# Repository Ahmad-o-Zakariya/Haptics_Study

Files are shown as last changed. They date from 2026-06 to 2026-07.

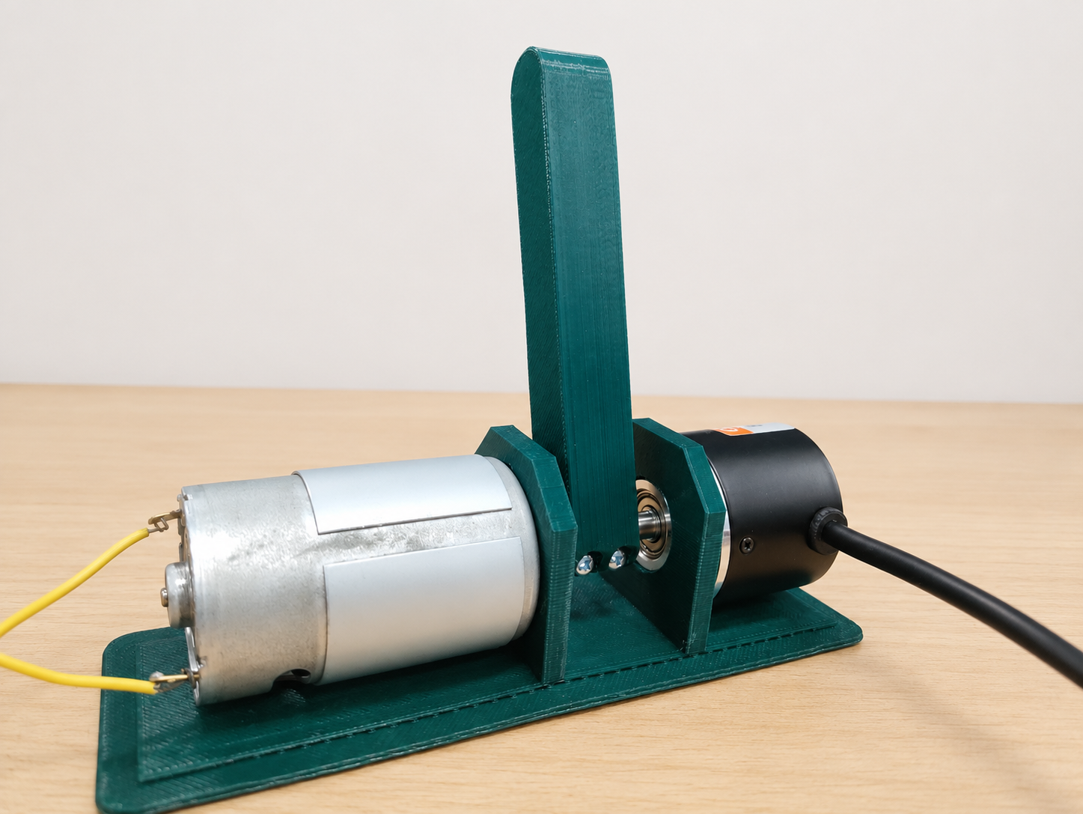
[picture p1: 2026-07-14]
1_kHz_haptic_control_loop/1 DOF Haptic setup.png

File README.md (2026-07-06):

# Haptics_Study

A collection of embedded haptic rendering experiments developed on the **ATmega328P (Arduino Uno)** platform. This repository documents the evolution of a **1-DOF force-feedback haptic interface**, from a production-grade virtual wall renderer to advanced research implementations including **fractional-order viscoelastic models**, **dual-rate control**, **direct port manipulation**, and multiple motor driver configurations.

The project began as a high-performance virtual wall implementation and has since evolved into a research platform for studying real-time embedded haptic rendering, control system stability, and computational optimization on resource-constrained microcontrollers.

Following successful validation and technical review by senior faculty, the original virtual wall implementation was officially approved as the benchmark instructional demonstration layout for incoming first-year engineering students.

---

# 📂 Repository Structure

```text
Haptics_Study/
│
├── 1_kHz_haptic_control_loop/
│   └── 1_kHz_haptic_control_loop.ino
│
├── Direct_Port_Manipulation/
│   └── Direct_Port_Manipulation.ino
│
├── Dual_Rate_FO-SLS_model/
│   └── Dual_Rate_FO-SLS_model.ino
│
├── Fractional_Order_Kelvin_Voigt_Model/
│   ├── Fractional_Order_Kelvin_Voigt_Model.ino
│   ├── graphs.py
│   └── haptic_plotter.py
│
├── Fractional_Order_SLS-Model/
│   ├── Fractional_Order_SLS-Model.ino
│   └── simulation_test.py
│
├── LMD18200T_Code/
│   └── LMD18200T_Code.ino
│
├── MD10C_R3_Code/
│   └── MD10C_R3_Code.ino
│
├── 3d-drawings/
│   └── Mechanical CAD (.stl) files
│
├── Paper and Notes/
│   └── Research papers, technical reports, lecture notes
│
├── haptic_with_noise.ino
└── README.md
```

---

# 📁 Project Overview

## 1️⃣ 1_kHz_haptic_control_loop

The primary production implementation.

**Features**

- Deterministic **1 kHz real-time control loop**
- Native **32-bit integer arithmetic**
- Embedded **2nd-order Butterworth low-pass filter**
- Passivity constraint protection
- Downsampled telemetry
- Optimized for the **L298N** motor driver

This serves as the baseline implementation for the remainder of the repository.

---

## 2️⃣ Direct_Port_Manipulation

Experimental implementation replacing Arduino API calls with direct manipulation of AVR hardware registers.

**Goals**

- Reduced instruction latency
- Lower interrupt overhead
- Faster GPIO transitions
- Improved deterministic timing

---

## 3️⃣ Fractional_Order_SLS_Model

Implements a **Fractional-Order Standard Linear Solid (FO-SLS)** virtual wall model.

Unlike a traditional spring-damper wall, this model captures viscoelastic behavior using fractional calculus, allowing more realistic rendering of compliant materials.

Includes simulation utilities for validating model behavior.

---

## 4️⃣ Fractional_Order_Kelvin_Voigt_Model

Implements a **Fractional Kelvin-Voigt** viscoelastic virtual environment.

Includes Python utilities for:

- Force visualization
- Experimental plotting
- Offline analysis

---

## 5️⃣ Dual_Rate_FO-SLS_Model

Experimental implementation combining:

- Dual-rate sampling
- Fractional-order viscoelastic rendering

to investigate stability improvements under computational constraints.

---

## 6️⃣ LMD18200T_Code

Version of the controller adapted for the **LMD18200T** high-current motor driver.

Designed for applications requiring:

- Higher continuous current
- Improved efficiency
- Industrial-grade motor control

---

## 7️⃣ MD10C_R3_Code

Alternative implementation supporting the **Cytron MD10C R3** motor driver.

Provides compatibility with PWM/Direction control architectures.

---

## 8️⃣ haptic_with_noise.ino

Legacy implementation preserved for educational comparison.

Characteristics:

- Floating-point computations
- Backward-difference velocity estimation
- Unrestricted serial logging
- Unstable loop timing

Useful for demonstrating common real-time control pitfalls.

---

## 9️⃣ 3d-drawings

Contains all mechanical CAD models used throughout development.

Includes multiple revisions of:

- Motor couplers
- Encoder couplers
- Shaft assemblies
- Handle assemblies
- Mounting structures

The designs evolved toward minimizing backlash while maximizing torsional rigidity.

---

## 📚 Paper and Notes

A curated collection of:

- Journal papers
- Conference publications
- Thesis material
- Technical reports
- Engineering notes

covering:

- Haptic rendering
- Fractional-order control
- Dual-rate systems
- Virtual wall stability
- Motor control
- Wave-variable haptics
- Embedded control

These documents served as the primary research references throughout development.

---

# ⚡ Hardware Configuration (Baseline L298N System)

## Power Supply

**MIMY RoHS S-120-12**

Provides:

- 12 V DC
- 10 A maximum current

| Terminal | Connection |
|---|---|
| L | AC Live |
| N | AC Neutral |
| Earth | Safety Ground |
| -V | L298N Ground |
| +V | L298N +12V |

---

## L298N Driver

| Pin | Connection |
|---|---|
| 12V | Power Supply +12V |
| GND | Common Ground (Power Supply + Arduino) |
| 5V | Not Connected |
| ENA | Arduino Pin 5 (PWM) |
| IN1 | Arduino Pin 4 |
| IN2 | Arduino Pin 7 |
| OUT1 / OUT2 | DC Motor |

PWM is applied through **ENA**, while **IN1/IN2** determine motor direction.

---

## Optical Quadrature Encoder

Base resolution:

**400 PPR**

Effective resolution:

**1600 Counts Per Revolution (4× decoding)**

| Encoder | Arduino |
|---|---|
| VCC | 5V |
| GND | GND |
| Phase A | Pin 2 (Interrupt 0) |
| Phase B | Pin 3 (Interrupt 1) |

---

# 🧠 Engineering Development Journey

## Phase 1 — Eliminating the Serial Bottleneck

High-frequency `Serial.print()` operations saturated the UART transmit buffer, reducing the control loop from **1 kHz** to approximately **400 Hz**.

**Solution**

- Decoupled telemetry from control calculations
- Downsampled serial output to **40 Hz**
- Maintained deterministic **1 kHz** execution

---

## Phase 2 — Correct PWM Architecture

Early implementations modulated PWM through direction pins, producing asymmetric motor behavior and excessive dynamic braking.

**Solution**

- Fixed digital direction lines (`IN1`, `IN2`)
- PWM exclusively through `ENA`

---

## Phase 3 — Velocity Filtering

Backward-difference differentiation amplified encoder quantization noise.

**Solution**

A second-order Butterworth IIR low-pass filter configured with:

- Sampling frequency: **1000 Hz**
- Cutoff frequency: **100 Hz**

This significantly reduced quantization artifacts while preserving low phase delay.

---

## Phase 4 — Integer Arithmetic Optimization

The ATmega328P lacks hardware floating-point support.

The controller was rewritten entirely in native integer count space, reducing computational overhead and improving deterministic execution.

---

## Phase 5 — Transparency vs Stability

Adding ambient damping improved stability but reduced free-space transparency.

The production implementation therefore omits background damping, relying instead on:

- Optimized controller gains
- Mechanical damping
- Rigid zero-backlash transmission

to preserve a natural haptic experience.

---

# 🛠️ Virtual Wall Model

The unilateral virtual wall is represented by a discrete spring-damper model:

$$
F_{\text{wall}} = -(K \Delta x + B\,v_{\text{filtered}})
$$

where force is generated only after the handle penetrates the virtual wall boundary.

### Baseline Parameters

| Parameter | Value |
|---|---|
| Wall Position | 400 counts (90°) |
| Stiffness | 22.5 PWM/count |
| Damping | 0.09 PWM/count/s |
| Maximum PWM | 200 |

---

# 🎯 Research Topics Covered

This repository explores multiple aspects of embedded haptic rendering, including:

- Classical virtual wall rendering
- Fractional-order viscoelastic modeling
- Standard Linear Solid (SLS) models
- Kelvin-Voigt models
- Dual-rate haptic rendering
- Direct AVR register manipulation
- Embedded real-time optimization
- Motor driver comparison (L298N, MD10C, LMD18200T)
- Mechanical transmission design
- Stability and passivity analysis
- Digital filtering
- Low-latency control systems

---

# 📄 License

This repository is intended for educational, research, and instructional use. Contributions and experimentation are encouraged.

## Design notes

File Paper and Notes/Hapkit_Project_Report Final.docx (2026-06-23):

Precision-Engineered Hapkit for Enhanced Haptic Feedback

Final Year Project Report

Submitted to the Department of Mechanical Engineering

In the partial fulfilment of the

Requirements for the degree of

Bachelor of Technology (B.Tech)

Isha Zargar

Maria

Supervised by:

Prof. Babar Ahmad

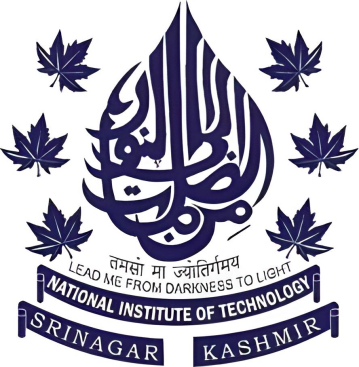
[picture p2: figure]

Department of Mechanical Engineering

National Institute of Technology

Srinagar—190006 India

July 2025

Declaration

We certify that:

a. The work contained in this report is original and has been done by us under the guidance of our supervisor.
b. The work has not been submitted to any other institute for any degree or diploma.
c. We have followed the guidelines provided by the institute in preparing the report.
d. We have conformed to the norms and guidelines given in the Ethical Code of Conduct of the Institute.
e. Whenever we have used materials (data, theoretical analysis, figures, and text) from other sources,
f. We have given due credit to them by citing them in the text of the report and giving their details in the references.

Further, we have taken permission from the copyright owners of the sources whenever necessary.

Isha Zargar (2021BMEC039)

Maria (2021BMEC037)

Certificate

This is to certify that the project work contained in the project report titled “Precision Engineered Hapkit for Haptic Feedback” submitted by “Isha Zargar and Maria” to the Department of Mechanical Engineering, National Institute of Technology Srinagar, J&K, India, is a record of bonafide project work carried out by them under my supervision and guidance and is worthy of consideration for the award of the degree of Bachelor of Technology in Mechanical Engineering of the Institute.

Supervisor

Professor Babar Ahmad

Co-Supervisor

Dr Suhail G. Khosa

Head of Department

Dr MF Wani

Date:

# Abstract

Haptics, the study and application of tactile feedback technology, plays a vital role in enhancing human interaction with machines, particularly in fields that demand precision and intuitive control. With applications spanning medical training, virtual reality, and remote manipulation, haptic devices serve as essential tools for simulating real-world physical interactions within digital environments.

This report presents the development and implementation of a haptic interface using a Hapkit — a low-cost, open-source, one-degree-of-freedom haptic device designed by Stanford University. The objective of this project was to assemble, calibrate, and program the Hapkit to demonstrate force feedback in real time, allowing users to interact with a virtual environment through physical motion. The design includes custom 3D-printed components, a DC motor, an optical sensor for position tracking, and an Arduino-based control system to regulate force rendering based on user input.

The project emphasizes accessibility and modularity, allowing further experimentation in human-computer interaction, motor learning, and virtual training scenarios. By successfully integrating mechanical design, sensor feedback, and control programming, this work demonstrates how haptic technology can be both educational and impactful, paving the way for deeper exploration in the rapidly growing field of tactile feedback systems.

# Acknowledgments

First and foremost, we express our deepest gratitude to the Almighty for granting us the strength, determination, and perseverance to successfully complete our final year project. We are profoundly thankful to our project supervisor, Prof. Babar Ahmad, Department of Mechanical Engineering, NIT Srinagar, for his invaluable guidance, constant encouragement, and unwavering support throughout the course of this project. His deep insight and belief in our capabilities were instrumental in navigating challenging phases of our work.

We also extend our sincere thanks to Prof. M.F.Wani, Head of the Department of Mechanical Engineering, NIT Srinagar, for providing us with essential departmental resources and a conducive environment to carry out our research.

A special note of appreciation goes to Dr. Suhail G Khosa at the Haptics and Mechatronics Devices (HAMD) Lab, whose assistance and expertise significantly contributed to the successful execution of this multidisciplinary project.

Isha Zargar (2021BMEC039)

Maria (2021BMEC037)

# List of Figures

# 2 Introduction

## 2.1 Overview of Haptics:

"Haptics" is derived from the Greek verb "haptesthai," which pertains to the sense of touch. Within the realms of psychology and neuroscience, haptics encompasses the investigation of human perception and manipulation of objects via tactile sensory modalities. This field incorporates kinesthetic sensors, which are responsible for detecting force and position, as well as cutaneous sensors, which are tasked with recognizing tactile sensations. The sense of touch can be categorized as either cutaneous or kinesthetic, contingent upon the type of neural inputs received by the brain. The cutaneous (tactile) system employs receptors located within the skin, whereas the kinesthetic system utilizes receptors found in muscles, tendons, and joints.

Haptics represents a significant area of research in robotics and virtual reality, focusing on the examination of tactile interactions—both physical and virtual—among humans, robots, and real or simulated environments. The integration of haptic technology with robotics is largely attributed to its reliance on advanced mechatronic systems. Haptic interfaces harness mechatronic devices and computerized controls to replicate or enhance the tactile sensations associated with perceiving or manipulating objects in the physical domain. This capability to reproduce authentic physical experiences or to generate entirely novel sensations greatly augments human-computer interaction (HCI) and the modalities of our interactions with technology.

## 2.2 Significance of Haptic Technology

Haptic technology refers to the field of science that bridges the gap between mechanical systems and the human sense of touch. It enables users to receive tactile sensations—such as pressure, vibration, or resistance—through an interface that replicates real-world interactions within virtual environments. This process, known as haptic feedback, allows for a two-way flow of information between human users and digital systems, where virtual responses are physically felt by the user based on the simulated environment.

The primary objective of haptics is to enhance realism in simulations and improve user immersion by mimicking the sensations encountered during real-life interactions. Through the integration of actuators and sensors, haptic systems replicate the feel of manipulating physical objects—even when they only exist in digital form. Haptic technology has grown beyond its initial applications in gaming and consumer electronics to become a cornerstone in fields such as medical training, robotics, virtual reality (VR), rehabilitation, and education. By enabling physical interaction with digital systems, haptics facilitates intuitive control, enhanced realism, and muscle memory development—attributes that are critical in both professional and learning environments.

For instance, haptic feedback systems are increasingly employed in rehabilitative devices aimed at aiding stroke survivors or patients with motor impairments; for example, exoskeleton gloves fitted with force feedback mechanisms allow users to regain lost hand movement by mimicking natural motion and providing resistance during therapy. This method encourages muscle reactivation and neuroplasticity.

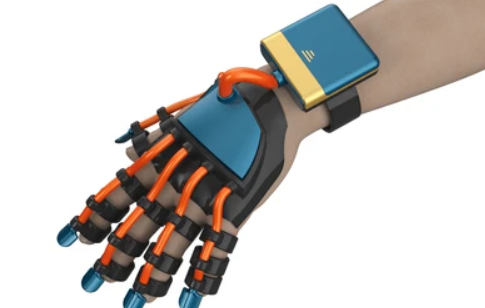
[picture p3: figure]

Figure 1: Exoskeleton Gloves

Moreover, advanced prosthetic limbs equipped with haptic sensors allow amputees to perceive pressure, texture, or even temperature. Sensors on the artificial limb send signals back to the residual limb, often through vibration or electrical stimulation, offering a more intuitive control experience.

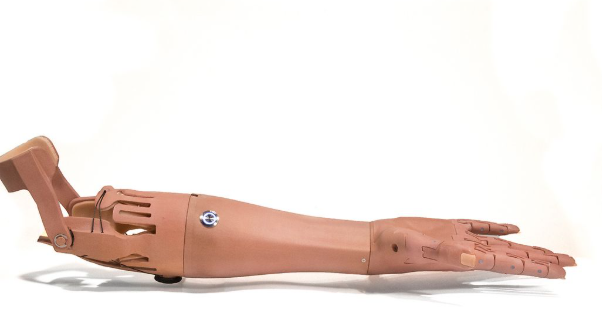
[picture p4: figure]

Figure 2 Advanced Prosthetic Limbs

Rehabilitation is one of the most promising frontiers for haptic technology. Patients recovering from neurological disorders like stroke or cerebral palsy often require repetitive motor training with physical guidance. As illustrated in, digital virtual environments are full of tools that enhance user immersion and decision-making processes, including haptic devices.

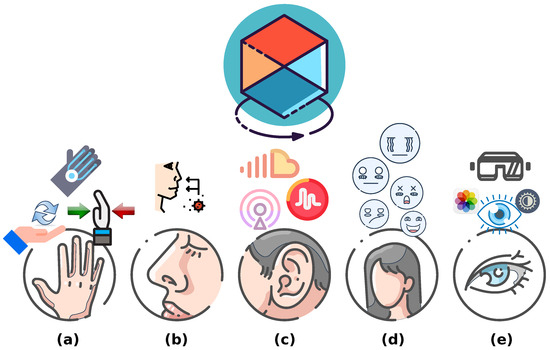
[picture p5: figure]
Sensors 24 06946 g001

Figure 3. Environment–user virtual interactions: (a) Touching: Generating sensations such as pain, pressure, temperature, etc. (b) Smelling: Producing sensitivity to odors, aromas, flavors, etc. (c) Listening: Transmitting sounds, rhythms, tunes, etc. (d) Feelings: Eliciting emotions and a comfortable atmosphere. (e) Vision: Generating accessible virtual environments.

Similarly, the gaming industry has seen a dramatic transformation with the integration of haptic technologies. Haptic devices enrich the gaming experience by simulating realistic touch sensations corresponding to in-game events. These sensations can include vibrations, resistance, textures, and force feedback, making the virtual environment feel physically tangible. For instance, Razer Freyja (Figure 4) is a computer chair pad that allows players to experience physical vibrations while gaming. The device provides realistic tactile sensations that match the events in the game, from the vibration of a race car engine to the tense silence during a covert mission.

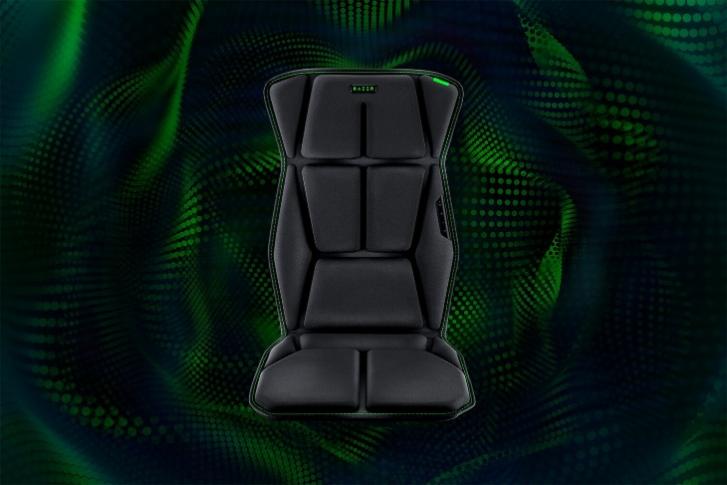
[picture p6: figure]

Figure 4 Razer Freyja Gaming Pad

In traditional console and mobile games, basic vibration motors in controllers or smartphones provide feedback when, for example, a player crashes a car, takes damage, or fires a weapon. However, with the advent of advanced haptic interfaces like haptic vests, gloves, and exoskeleton controllers, players can now feel the direction and intensity of impacts, the recoil of weapons, or the resistance of drawing a bowstring. This significantly enhances immersion and engagement. One of the examples is Sony’s PlayStation 5 DualSense controller (Figure 5). The device not only relies on voice coil actuators, but the adaptive triggers are also powered by an additional DC motor. This transmits additional active haptic feedback, like increased resistance or actively pushing against the finger, using a gear mechanism.

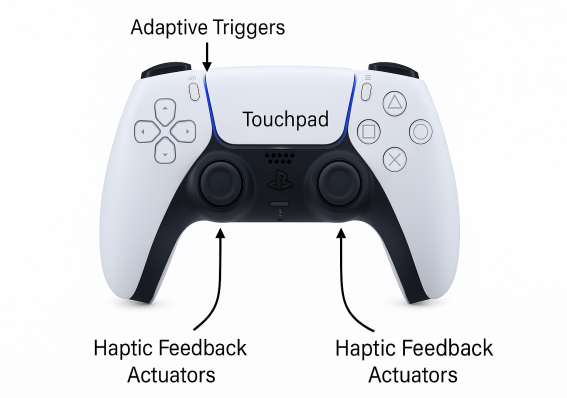
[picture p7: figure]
Generated image

Figure 5 Sony’s PlayStation 5 DualSense controller

In VR and AR systems, haptics plays a central role in bridging the gap between the digital and physical worlds. While visual and auditory inputs allow users to perceive virtual environments, haptic feedback makes it possible to interact with them meaningfully. This interaction is essential for a complete sense of “presence”—the psychological feeling of truly being inside the virtual space. Furthermore, full-body haptic suits (like the Tesla suit) are being developed to deliver feedback across multiple body zones, enabling users to experience environmental conditions (e.g., heat, cold, wind) or physical impacts across their entire body.

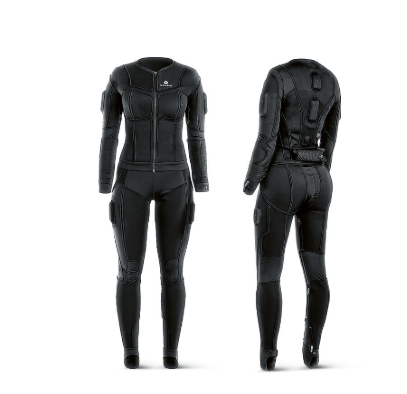
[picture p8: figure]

Figure 6: The Tesla Suit

## 2.3 Major Research Domains in Haptic Technology

Haptics is a multidisciplinary field with diverse research areas that explore how humans perceive and interact with their environment through the sense of touch. Broadly, research in haptics can be categorized into three interconnected domains:

- Human Haptics
- Machine Haptics
- Computer Haptics

Figure 7 illustrates the interconnected domains of haptics research.

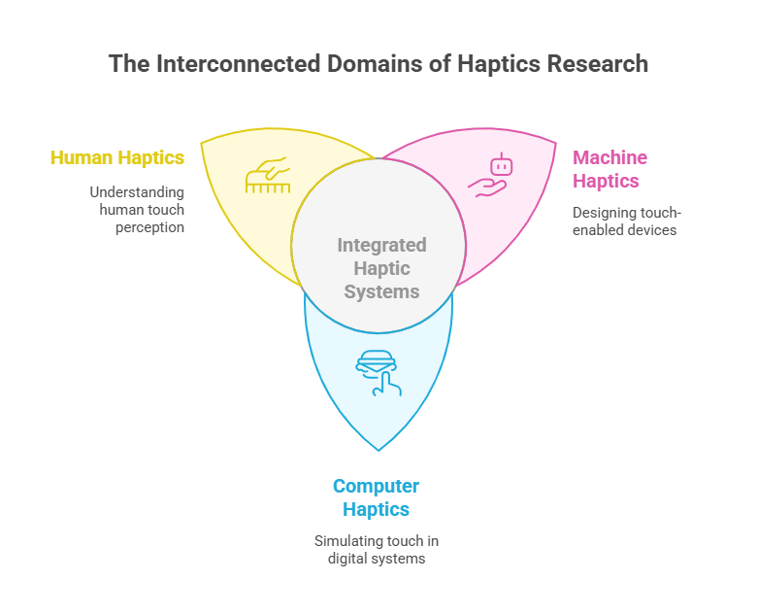
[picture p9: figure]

Figure 7: The Interconnected Domains of Haptics Research

### 1.3.1 Human Haptics

Human haptics is a rich and interdisciplinary research area that focuses on how humans perceive, interpret, and respond to physical interactions through the sense of touch. It encompasses both tactile sensations, which arise from contact with the surface of the skin, and kinaesthetic sensations, which are associated with movement, force, and position of the muscles and joints. Figure 8 illustrates the biological mechanism of touch (haptic perception). When the skin encounters an object (stimulus), sensory receptors located in the dermis detect the mechanical interaction. These receptors send signals through nerves, which carry the information to the brain via neural pathways. The brain then processes these signals, resulting in the perception of touch, such as texture, pressure, or temperature. The inset shows a magnified view of the skin layers, highlighting the role of sensory receptors and nerves in initiating the haptic feedback loop.

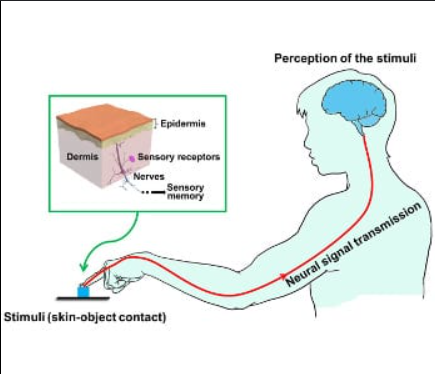
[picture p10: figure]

Figure 8: Neural pathway of haptic perception: from skin contact to brain interpretation.

The study of human haptics draws from various scientific domains, including neurophysiology, cognitive psychology, biomechanics, and sensory neuroscience, to understand how the human body receives and processes haptic information. This understanding is critical not only for building accurate models of human perception but also for designing responsive systems in fields like robotics, virtual reality, prosthetics, and rehabilitation.

At the core of human haptic perception is the human sensorimotor loop, which integrates sensory input and motor output to create a cohesive interaction with the environment. When a person touches or manipulates an object, specialized sensory receptors in the skin and deeper tissues are activated. These mechanoreceptors include Merkel cells, which respond to sustained pressure and texture; Meissner’s corpuscles, which detect light touch and dynamic changes in skin deformation; Ruffini endings, which are sensitive to skin stretch and help with the perception of hand shape and motion; and Pacinian corpuscles, which respond to high-frequency vibrations. Each type of receptor plays a unique role in gathering detailed and layered information about the object being touched, such as its size, shape, texture, weight, and movement.

Once these receptors are activated, they transmit electrical signals via peripheral nerves to the central nervous system. The signals pass through the spinal cord and are processed in various areas of the brain, particularly the somatosensory cortex, which is responsible for interpreting touch, pressure, temperature, and proprioception (the sense of body position and movement). This complex and highly organized pathway ensures that haptic information is rapidly analyzed, integrated with other sensory data (such as vision), and converted into an appropriate motor response. The motor system then generates corresponding muscle commands to carry out actions like grasping, lifting, adjusting grip, or withdrawing the hand in case of discomfort or danger. This bidirectional flow of sensory and motor information forms a feedback loop that enables humans to interact with their surroundings in a precise, adaptive, and intuitive manner.

The insights gained from studying human haptics have significant real-world applications. One prominent area is in the development of advanced prosthetic limbs that provide tactile or force feedback, allowing users to regain a sense of touch and better control their artificial limbs (Figure 9)

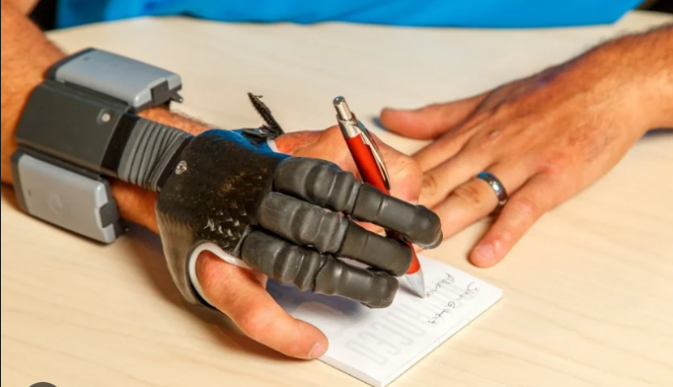
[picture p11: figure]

Figure 9 Prosthetic Technology/Arm Dynamics

Human haptics also plays a critical role in neurological rehabilitation, where haptic stimuli are used to retrain motor pathways in patients recovering from stroke, injury, or neurodegenerative conditions. In the realm of cognitive psychology, researchers use haptic tasks to study learning, memory, spatial reasoning, and perceptual development, particularly in children or individuals with visual impairments. Moreover, industries focused on ergonomic design—such as automotive, consumer electronics, and industrial tools—use knowledge of human haptics to create products that are more comfortable, intuitive, and responsive to human touch.

In conclusion, human haptics is the biological and psychological foundation upon which all haptic technology is built. By studying the intricacies of how humans sense and interpret touch, researchers and engineers can develop more natural, effective, and inclusive systems for communication and control, spanning everything from medical devices to immersive virtual environments.

### 1.3.2 Machine Haptics

Machine haptics is a foundational domain within the field of haptic technology that focuses on the design, development, and deployment of electromechanical systems capable of reproducing or augmenting the sense of touch. These systems, commonly known as haptic devices or haptic interfaces, form the physical layer that connects human users to digital or remote environments. Their core function is twofold: they detect and measure human input—such as hand position, motion, or applied force—and respond by delivering appropriate tactile or kinaesthetic feedback. In doing so, machine haptics creates an interactive feedback loop that simulates the mechanical and sensory properties of real-world interactions. This not only enhances realism in virtual experiences but also enables humans to interact safely and effectively with objects or environments that are distant, dangerous, or otherwise inaccessible.

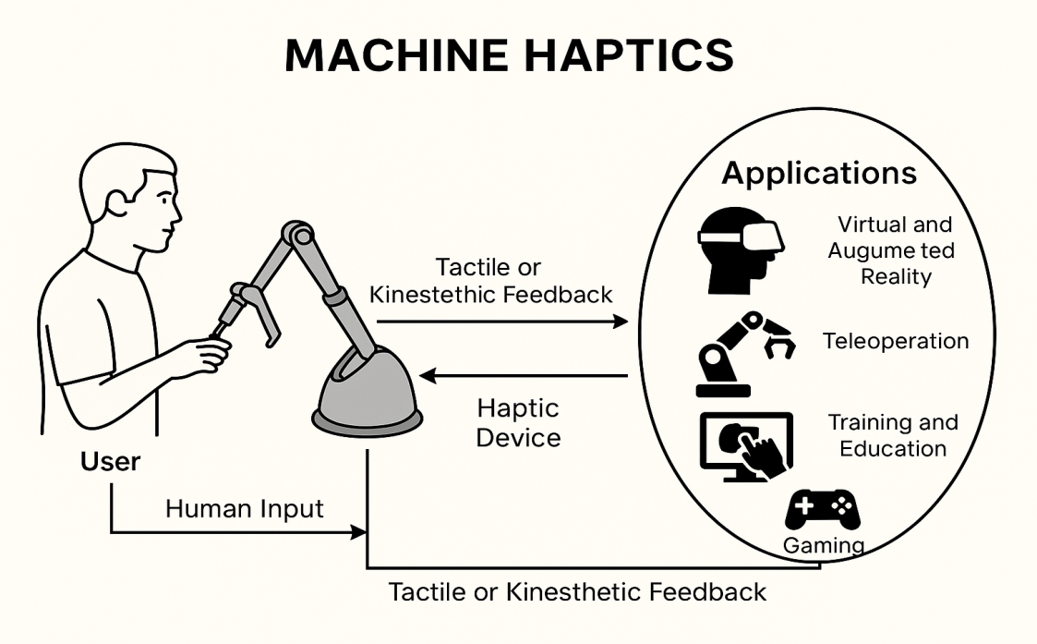
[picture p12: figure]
Generated image

Figure 10:

Schematic representation of machine haptics: Illustrates the interactive feedback loop between user input and electromechanical haptic output, central to realistic touch-based experiences in virtual or remote environments.

Machine haptics finds application in a wide variety of fields. In virtual reality (VR) and augmented reality (AR), haptic devices add a physical layer to visual immersion, enabling users to touch and manipulate digital content as if it were real. In teleoperation, such as robotic surgery or remote exploration, haptic interfaces allow operators to control distant robotic systems while receiving real-time tactile feedback. improving precision and safety. In training and education, haptic systems provide hands-on practice in environments that are too expensive, risky, or rare to replicate physically. Additionally, industries such as gaming, automotive design, rehabilitation, and assistive technology are increasingly adopting machine haptics to create more intuitive and engaging user experiences.

Thus, machine haptics represents the mechanical and interactive side of haptic technology. By enabling physical feedback that responds to user input, it serves as a crucial link between the human body and digital or remote environments. Whether enhancing realism in simulations or enabling complex remote operations, machine haptics continues to expand the boundaries of human-machine interaction.

### 1.3.3 Computer Haptics

Computer haptics is a crucial research area within the field of haptic technology that deals with the creation of software and algorithms responsible for simulating touch-based interaction in virtual environments. Unlike human haptics, which focuses on the sensory-motor pathways of the human body, and machine haptics, which involves the design of physical devices, computer haptics is primarily concerned with the virtual experience of touch. It determines how digital objects should behave when interacted with, how collisions should be detected, and how the resulting forces should be computed and sent back to the user via a haptic device. The core objective of computer haptics is to make virtual interactions feel real by offering precise and stable force feedback in real time. This process of simulating the sense of touch digitally is referred to as haptic rendering, which is the touch-based counterpart of graphical rendering.

Haptic rendering consists of several integral components. The first is avatar representation, which refers to the virtual model of the haptic device or the user’s tool within the simulated environment. This avatar moves in accordance with the user’s physical motions and is the medium through which the user interacts with virtual objects (Figure 12).

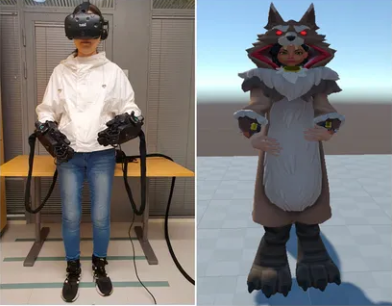
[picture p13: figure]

Figure 11: A user equipped with VR and haptic devices (left) controls a virtual character (right), enabling immersive interaction and touch feedback in a virtual environment

Different types of avatars exist depending on the application and computational capability of the system. A point-based avatar, which has three degrees of freedom (3-DOF), is the simplest and is commonly used due to its computational efficiency. More advanced applications may use object-based avatars with six degrees of freedom (6-DOF), enabling full orientation and manipulation of 3D virtual objects. Additionally, multipoint avatars allow the simulation of more complex grips, such as those involving multiple fingers, while volumetric avatars are employed in high-precision tasks such as surgical simulations to represent instruments used for cutting, drilling, or probing inside the human body.

Another essential part of computer haptics is collision detection. This module determines when and where the avatar contacts a virtual object. The accuracy and speed of this detection process are vital, as any lag can disrupt the user's immersive experience and make the force feedback feel unnatural. In complex virtual environments, collision detection becomes computationally intensive due to the presence of numerous objects and surfaces. To improve performance, techniques like hierarchical bounding volumes are used. These reduce the complexity of calculations by focusing on detecting collisions in the immediate proximity of the avatar instead of checking every object in the environment. This significantly reduces the workload and speeds up the process without sacrificing accuracy.

Once a collision is detected, the force response algorithm is triggered. This algorithm is responsible for calculating the type, direction, and intensity of force that should be rendered to the user through the haptic device. The algorithm takes into consideration various factors such as the penetration depth—how deeply the avatar has entered the virtual object—and the surface properties of the object, including stiffness, texture, friction, and roughness. The goal is to generate realistic force feedback that accurately mimics how the object would feel if touched in the real world. For example, interacting with a rubbery surface should feel soft and elastic, while touching a metallic object should give a harder, more resistant sensation.

Lastly, a key feature of computer haptics is its bidirectional interaction capability. Haptic systems don’t just send feedback to the user; they also continuously receive input from the user through the haptic device. This forms a closed loop where energy and information flow in both directions—user to computer and computer to user. To ensure a smooth and stable experience, this loop must operate at extremely high update rates, typically over 1 kHz (1000 updates per second). Any lag in this loop can result in unstable or jerky feedback, which can degrade the overall interaction experience and even pose safety issues in sensitive applications like robotic surgery. Therefore, advanced haptic control algorithms are implemented to ensure system stability, especially in devices that are low-power or have limited mechanical strength.

In conclusion, computer haptics plays a fundamental role in bridging the gap between the virtual and physical worlds. It provides the software backbone that enables users to physically feel computer-generated environments. Whether in medical simulation, virtual prototyping, gaming, or remote robotic control, computer haptics ensures that the forces and tactile sensations felt by the user are both realistic and responsive, enhancing immersion, precision, and interactivity in virtual systems.

## 2.4 Haptic Devices: An Overview

Haptic devices are sophisticated electromechanical systems that form the essential hardware component of any haptic interaction. These devices are specifically engineered to establish a physical connection between a user and a virtual or remote environment by simulating the sense of touch. They function as a medium that enables the user to both input physical actions (such as movement or applied force) and receive corresponding tactile or kinaesthetic feedback. By doing so, they effectively close the loop between human physical actions and computer-generated responses, allowing users to feel what they see in a digital domain.

At a functional level, a haptic device is composed of several core components that work together to facilitate interactive touch-based communication. Sensors within the device track parameters such as position, velocity, orientation, and applied force by the user. These sensors may include potentiometers, encoders, force-sensitive resistors, and inertial measurement units, all of which convert mechanical inputs into digital signals. Actuators are then used to produce feedback by generating mechanical stimuli that can be felt by the user. These stimuli can be in the form of vibrations, forces, or temperature changes and are commonly generated using motors, piezoelectric actuators, or vibrotactile elements. The entire system is coordinated by a real-time control unit, often powered by microcontrollers or embedded processors, which processes the sensor data, computes the appropriate feedback, and ensures the system's responsiveness and stability. The physical structure of the device—which may include robotic arms, linkages, or wearable gloves—serves to transmit forces and movements between the device and the user. Figure 11 illustrates the components of a haptic device precisely.

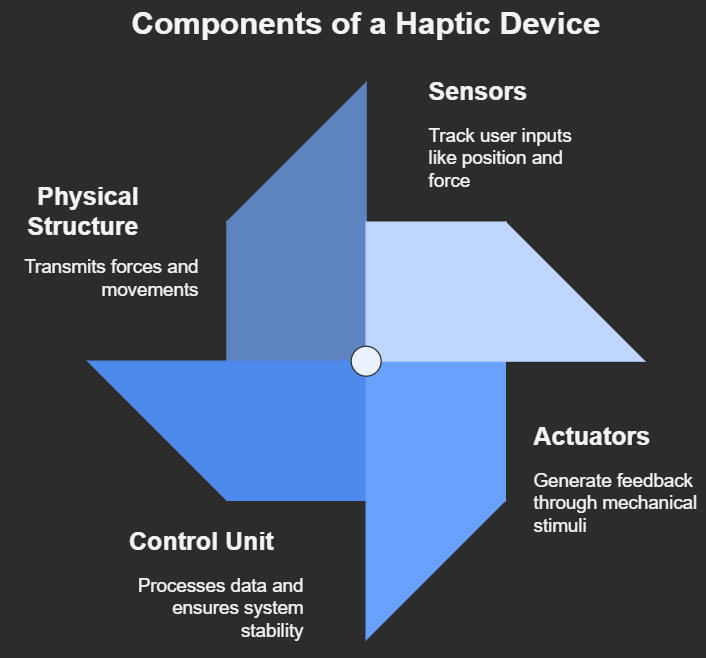
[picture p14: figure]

Figure 12: Components of Haptic device

Haptic devices are generally categorized based on the type of feedback they deliver.

- Force feedback devices simulate mechanical properties such as resistance, weight, inertia, or compliance. These devices usually operate like robotic arms or actuated linkages that push or pull against the user’s hand or fingers in response to virtual interactions. For example, when a user tries to push a virtual object, a force feedback device resists the motion to mimic the object’s stiffness or weight. This allows the user to "feel" the object as if it were physically present. Force feedback is crucial in applications where physical manipulation and precise control are required—such as surgical simulators, robotic arms for space or hazardous environments, or immersive virtual prototyping. One such examples is the Phantom omni force feedback device (Figure 10)

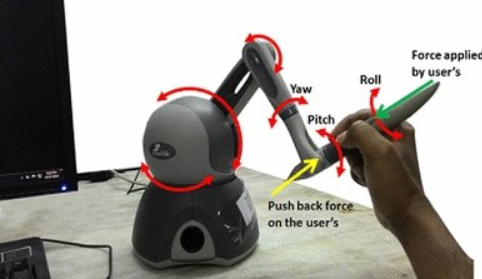
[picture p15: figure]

Figure 13 :Phantom Omni Force Feedback Device

Figure 10 shows the Phantom Omni Force Feedback Device with a stylus held by the user. As the user applies force and moves the stylus, the device senses motion in yaw, pitch, and roll directions. In response, it applies a push-back force using motors, letting the user feel virtual surfaces or resistance. This simulates real touch in virtual environments.

- Tactile devices are focused on stimulating the skin’s surface with detailed sensations like vibration, pressure, temperature, or texture. These systems may use arrays of actuators, vibratory motors, pin arrays, or even thermal elements to reproduce the subtle cues that characterize how different materials and surfaces feel. For instance, a tactile display on a touchscreen can simulate the feeling of sandpaper or silk by modulating friction or micro-vibrations under the user’s finger. Similarly, a user feeling vibrations while touching a phone is also experiencing tactile feedback (Figure 11)

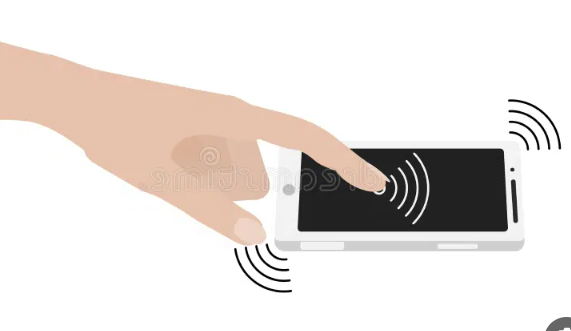
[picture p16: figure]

Figure 14: Hand Touching Smartphone

Tactile feedback is particularly valuable in consumer electronics, wearable devices, Braille readers, and any interface that requires the transmission of non-verbal, sensory-rich information through touch.

A critical performance parameter of haptic devices is their degrees of freedom (DOFs)—that is, the number of independent directions in which the device can move or exert force. A simple 1-DOF device might only allow back-and-forth movement along a single axis, while more advanced devices may support 3-DOF translation (X, Y, Z) and 3-DOF rotation (pitch, yaw, roll), totalling 6-DOF. The greater the number of DOFs, the more nuanced and realistic the haptic interaction becomes. Some high-end haptic interfaces used in research or industrial simulation can even support additional DOFs through modular or multi-fingered designs.

The utility of haptic devices spans across a wide range of domains. In the medical field, they are used for surgical simulation, dental training, and physical rehabilitation, allowing trainees and patients to interact with virtual tissues and instruments in a realistic manner. For example, the da Vinci Surgical Robot uses haptics to enhance precision and control during minimally invasive surgeries. While early versions lacked true haptic feedback, recent advancements incorporate force-sensing and tactile feedback systems that allow surgeons to feel resistance or tissue interaction through robotic instruments. This improves surgical accuracy, reduces tissue damage, and enhances the surgeon's sense of touch, making robotic-assisted procedures more intuitive and safer.

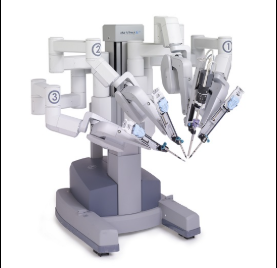
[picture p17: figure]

Figure 15: The da Vinci Surgical Robot

In the realm of teleoperation, haptic devices are employed to control robotic arms in remote or hazardous environments, such as deep-sea exploration, bomb disposal, or space missions. The gaming and virtual reality industries also benefit immensely from haptic technology, as it significantly enhances immersion by allowing players to feel in-game actions such as gun recoil, collisions, or object textures. Furthermore, haptic devices serve as invaluable tools in research and education, especially for teaching principles of dynamics, control systems, and perception. Designers and engineers Also, use Use haptic systems in digital prototyping, enabling them to “feel” and assess virtual products before committing to physical manufacturing.

## 2.5 Motivation

Haptic technology is steadily transforming how humans interact with machines by introducing tactile and force feedback into digital experiences. Despite its rapid evolution, haptics remains relatively underutilized in affordable educational tools and accessible rehabilitation devices. The current market is saturated with high-cost, high-fidelity haptic devices such as the Geomagic Touch (formerly Phantom Omni), which, while excellent for research and industry-grade simulation, are far from practical for widespread use in schools, developing regions, or home-based therapy setups. This disparity highlights a growing need for cost-effective, compact, and modifiable haptic interfaces that can be used both in resource-constrained environments and for specialized applications like motor rehabilitation and STEM education. Our project, inspired by the Hapkit initiative from Stanford University, seeks to fill this gap by developing a low-cost, 1-DOF rotary haptic device (Hapkit) that is both mechanically simple and electronically flexible. Unlike complex multi-DOF robotic arms, our Hapkit uses a rotary DC motor coupled with a flexure-based paddle, allowing for continuous smooth motion and force feedback within a single rotational axis. The system employs a custom-built drive mechanism based on a neoprene belt and replaces the traditional capstan or gear trains with harmonic drive-like arrangements to ensure near-zero backlash—critical for realistic haptic rendering. A precision potentiometer is used in place of a Hall-effect sensor to monitor angular displacement and enable closed-loop control.

The motivation behind developing this device lies in its versatility and inclusiveness. First, it has vast potential as a learning tool in engineering and science education. By integrating it with interactive software, students can gain hands-on experience with physics concepts like spring-damper systems, force fields, and kinematics. Instead of only observing simulations on a screen, they can physically feel forces and gain a kinaesthetic understanding — a powerful pedagogical advantage.

Second, the Hapkit could serve as an assistive tool for motor learning and rehabilitation. Individuals recovering from strokes or those with congenital motor disabilities often require repeated, guided hand motions to rebuild muscle memory and coordination. Our device allows for customizable, programmable resistance and guidance forces, simulating therapeutic environments tailored to individual progress. The low cost and portability also make it viable for home-based rehabilitation, bypassing the need for expensive clinics or long commutes.

Third, the simplicity of the device—in terms of hardware and software—opens it to open-source development and community-driven innovation. Students, hobbyists, and researchers can modify the firmware, experiment with different control algorithms, or adapt the mechanical design to include more degrees of freedom. This not only fosters an inclusive ecosystem of innovation but also ensures that the technology evolves organically with real user feedback.

Furthermore, the use of Arduino-compatible microcontrollers and readily available materials ensures that the device can be built and deployed even in educational institutions with limited infrastructure. The 3D-printed parts used for the structure allow for rapid prototyping and easy replication, while modularity makes it simple to replace or upgrade components such as the motor, belt, or sensors.

The motivation to build this haptic device also stems from the ongoing shift in how people interact with virtual and augmented realities. As industries and educational institutions adopt more immersive digital tools, the lack of tactile feedback remains a key limitation in ensuring full engagement. The Hapkit, though fundamentally simple, offers a gateway into this realm by delivering an affordable tactile experience that enhances user immersion and skill transfer.

## 2.6 Hapkit

The Hapkit is a one-degree-of-freedom (1-DOF) haptic device that utilizes a closed-loop belt drive system to provide high-resolution force feedback to the user. As shown in Figure 16, the mechanism consists of a semicircular rotating arm attached to a motor shaft through a neoprene timing belt, with motion sensed by a potentiometer mounted co-axially. This belt-and-pulley design replaces traditional rigid linkages, allowing smooth, low-backlash transmission of motion between the user's hand and the actuator. The arc-shaped link of the Hapkit restricts the motion to a planar rotational degree of freedom, which is ideal for demonstrating force-displacement relationships and simple haptic interactions. For our project, this device is used as a fundamental interface to sense user input motion and respond with controlled forces, enabling a variety of virtual environments to be simulated in one dimension. The feedback loop is closed using a real-time control algorithm implemented on an Arduino microcontroller, which reads the position data from the potentiometer, computes the appropriate feedback force, and drives the DC motor accordingly. The Hapkit’s compact design, simplicity of construction, and open-source support make it highly suitable for educational and experimental use in haptic applications. Unlike the pantograph, which permits 2-DOF planar movements, the Hapkit is more constrained but compensates with precision, lower inertia, and greater control over force rendering, which is critical for rendering virtual springs, walls, or damping fields with high fidelity. Its modular architecture also allows enhancements like force sensors or harmonic drives to be integrated for research applications requiring higher accuracy or zero backlash performance.

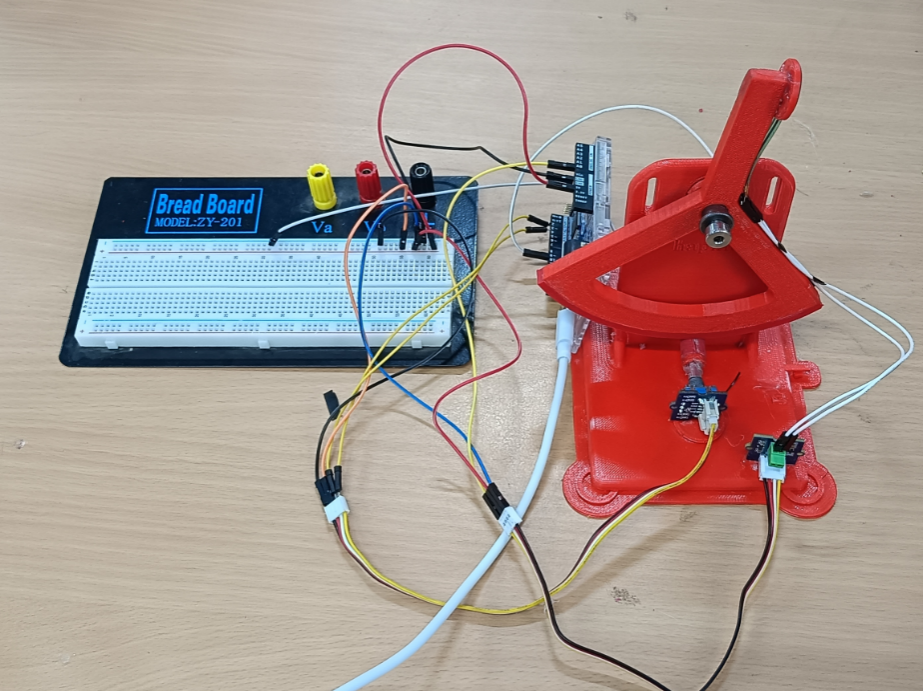
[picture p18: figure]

Figure 16: Final Prototype

# 3 Literature Review

Recent advances in haptic technology have significantly changed how humans interact with devices. Many of these discoveries have greatly influenced our project, providing both inspiration and practical insights.

Below are some key studies that have shaped our work:

1. Stanford University (ME327 Class): Stanford University offers an extensive course on haptics, focusing on the design, control, and applications of haptic devices. This foundational knowledge is critical for understanding the broader landscape of haptic technology.
2. Educational Haptics—Morimoto Lab: The Morimoto Lab at UC San Diego conducts research on educational haptics, including the development and application of the Hapkit. Their work focuses on creating low-cost, easy-to-assemble haptic devices to enhance learning in STEM fields.
3. Stanford University x Seeed: Open-Source Haptic Device for Affordable Haptics Education for All :This article details a collaboration between Stanford University and Seeed Studio to develop an all-in-one controller board for the Hapkit, significantly reducing costs and simplifying the assembly process. The initiative aims to make haptic education more accessible globally.
4. Melisa Orta Martinez, Cara M. Nunez, Ting Liao, and Tania K. Morimoto—Evolution an Analysis of Hapkit: An Open-Source Hapkit Device for Educational Applications: This research explores the development and optimization of Hapkit, a low-cost, open-source haptic device designed for educational use. By improving its mechanical design and system performance, the study highlights Hapkit’s potential for enhancing interactive learning in dynamics and control, as well as its broader applicability in accessible haptic education and training.
5. Alexandra Miller (https://www.researchgate.net/profile/Alexandra-Miller-14), Naveed D. Riaziat, and (https://www.researchgate.net/scientific-contributions/Naveed-D-Riaziat-2200068276) Jeremy D. Brown (https://www.researchgate.net/scientific-contributions/Jeremy-D-Brown-2200059408) - An Open-Source Ungrounded Hapkit for Educational Applications: The paper titled “An Open-Source Ungrounded Hapkit for Educational Applications” introduces a modified version of the original Hapkit haptic device, designed to provide ungrounded kinaesthetic feedback. Unlike traditional haptic devices that require a fixed base, this ungrounded variant can generate torque at the user's wrist without being anchored, enabling more versatile interactions in virtual environments.
6. Christopher Richard, Allison M. Okamura, and Mark R. Cutkosky—Getting a Feel for Dynamics: Using Haptic Interface Kits for Teaching Dynamics and Controls: This paper discusses the use of low-cost, single-axis force-reflecting joysticks to teach students about electromechanical systems, dynamics, and controls, emphasizing the value of hands-on learning.
7. Eloy Irigoyen, Mikel Larrea, Manuel Grana, A Narrative Review of Haptic Technologies and Their Value for Training, Rehabilitation, and the Education of Persons with Special Needs: This review examines the broad spectrum of haptic technologies, from force feedback to pseudo-haptics, and their applications in education, training, and rehabilitation, highlighting their growing importance in human–computer interaction.
8. Robert Bloom (https://www.researchgate.net/scientific-contributions/Robert-Bloom-2252464867), Zachary Huang (https://www.researchgate.net/scientific-contributions/Zachary-Huang-2281376018), Kaitlyn Lavarias (https://www.researchgate.net/scientific-contributions/Kaitlyn-Lavarias-2281359872), Tania K. Morimoto (https://www.researchgate.net/scientific-contributions/Tania-K-Morimoto-2057042836) - H 3 Kit: Hand-Held Haptic Kit for STEM Education: The conference paper presents the design and application of a novel, low-cost, open-source haptic device aimed at enhancing STEM education. Developed by researchers at UC San Diego, the H3Kit is a wearable, forearm-mounted device that provides kinaesthetic feedback through wrist flexion and extension movements. It enables users to interact physically with virtual environments, facilitating experiential learning of scientific and
9. Muhammad Fouad (https://sceee.journals.ekb.eg/?_action=article&au=638765&_au=Muhammad++Fouad), Tamer Mansour, and (https://sceee.journals.ekb.eg/?_action=article&au=638766&_au=Tamer++Mansour) Tamer Nabil—Use of haptic devices in education: A review: This comprehensive review discusses how haptic technology transforms passive learning into active, hands-on experiences, particularly beneficial in STEM education. It covers various haptic devices used across educational fields and addresses challenges in widespread adoption.
10. Melisa Orta Martinez—Design and analysis of open-source educational haptic devices: This doctoral dissertation presents an in-depth analysis of the design considerations and educational applications of open-source haptic devices, including the Hapkit. It provides valuable insights into the development process and pedagogical impact of such tools.

While many haptic devices exist in the commercial and research space, they are often overly complex and expensive for foundational educational purposes. Most are designed with three or more degrees of freedom, which makes them suitable for advanced applications but unnecessary for basic learning tasks like exploring force feedback, system dynamics, or control principles. This added complexity not only increases cost but also makes them harder to assemble, maintain, and integrate into classroom environments. In our review, we found that 1-DOF devices, which are sufficient for demonstrating core haptic concepts, are underrepresented in literature and rarely optimized for affordability and ease of use. With these factors in mind, our project focuses on building a 1-DOF, low-cost educational haptic device using motor actuation, designed to provide accurate and accessible hands-on learning in haptics for students and educators alike.

# 4 Design and Fabrication of a Hap Kit

## 4.1 Objective:

The objective of this project is to design and implement a low-cost, open-source haptic device using the Hapkit platform to provide kinaesthetic force feedback and resistance through virtual environmental interactions. The system will simulate features such as a virtual wall, enabling users to experience realistic physical boundaries and dynamic resistance. This interaction is achieved using an impedance-type control system, where the position of the user's input is continuously tracked to generate appropriate feedback forces. Such a setup aims to enhance user understanding of physical principles and control dynamics, making it particularly valuable for educational applications and virtual training environments.

## 4.2 Hardware

To achieve the objectives mentioned above, various transducers and components are utilized for determining position, computing force feedback, and providing output force to the user.

• Brushed DC Motor

• FRS Sensor

• Neoprene Drive

• Arduino Uno

Additionally, we have 3D- printed custom-designed structural parts that serve as the main body of our Hapkit.

The selection of each component is based on various parameters, which will be discussed in the following sections.

### 4.2.1 Brushed DC Motor:

For our application involving force feedback, we needed a motor to deliver sufficient torque to render virtual walls and forces accurately. Additionally, the motor required simple control using PWM (Pulse Width Modulation), which could be integrated with a high-resolution encoder to enhance position and velocity feedback precision.

A brushed DC motor is a flexible and economical choice for haptic applications in our Hapkit project, since customization and dynamic force feedback are our priorities. DC motors do not include built-in position feedback or control circuitry, requiring the use of external components such as encoders or potentiometers and motor drivers to implement closed-loop control. While this adds complexity, it also allows for greater design freedom and fine-tuning of haptic behaviour through custom control algorithms.

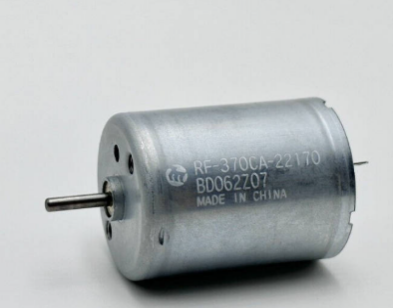
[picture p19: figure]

Figure 17: The RF-370CA motor

The RF-370CA is compact, lightweight, and operates effectively at low voltages (typically 3–12 V), making it well-suited for handheld educational devices. When integrated with a microcontroller and appropriate feedback mechanisms, this motor can simulate essential haptic effects such as spring forces, damping, or virtual walls by dynamically adjusting torque based on user input. Although it lacks the position-holding capabilities of a servo and introduces challenges like gear backlash and brush wear, the RF-370CA’s affordability, availability, and versatility make it a practical option for prototyping force-feedback systems where real-time responsiveness and adaptability are key. For our Hapkit, the RF-370CA serves as the actuator to create dynamic force sensations through motor-driven resistance and programmed interaction forces.

### 4.2.2 FSR Sensor:

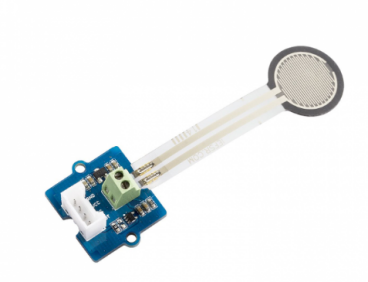
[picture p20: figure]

Figure 18: FSR402 (Force Sensitive Resistor)

The FSR402 (Force Sensitive Resistor) is a thin, flexible sensor that changes its electrical resistance based on the force applied to its surface. This makes it ideal for detecting human touch or applied pressure in interactive systems. It operates on a simple principle: as force increases, the resistance across the sensor decreases in a non-linear fashion. In its resting state (no pressure), the resistance is extremely high (>10 MΩ), but when pressed, it can drop to a few hundred ohms. The sensitive force range of the FSR402 typically spans from 0.2 N to 20 N, making it well-suited for detecting finger pressure or light mechanical contact.

Internally, the FSR402 consists of two film layers—one with conductive traces and another coated with a pressure-sensitive ink. When pressure is applied to the circular sensing area (approximately 12.7 mm in diameter), the conductive material makes better contact, reducing resistance. This change in resistance can be captured using a voltage divider circuit, which allows microcontrollers like Arduino to interpret the sensor’s output as an analog voltage signal.

In our Hapkit project, the FSR402 is strategically mounted on the handle or interaction surface where the user applies force during haptic tasks. Its primary function is to measure the intensity of user interaction—for example, how hard the user is pressing against a virtual wall or resisting a simulated spring force. This data will be read by the Arduino and used to modulate the force feedback delivered by the servo motor. For instance, if the user presses harder, the system can increase motor torque or stiffness, mimicking real-world material behavior. This not only enhances realism but also makes the system more responsive and adaptive.

Moreover, by logging this force input over time, the system can support training or rehabilitation applications, such as helping users build fine motor control or track progress in grip strength. The sensor is also useful for triggering specific haptic events—for example, switching from free movement to resistance once a threshold force is detected.

While the FSR402 is not suitable for precise force measurements due to hysteresis, drift, and non-linearity, it is highly effective in educational and low-cost interactive applications. Its ease of integration, low power requirements, and compact size make it an ideal addition to the Hapkit system, helping close the feedback loop between user input and haptic output.

### 4.2.3 Neoprene drive

Due to its low inertia, minimal backlash, high mechanical compliance, and structural simplicity, we have opted for neoprene drive as our preferred transmission method. In this system, a neoprene cable or belt serves as the key transmission medium, wound around the motor pulley and the driven pulley (the sector pulley) in multiple loops to create sufficient friction for torque transmission. This method, when executed properly, significantly amplifies torque while retaining smooth and continuous motion—attributes that are especially beneficial in force feedback in our Hapkit.

In many robotics and haptics systems, direct-drive motors alone—especially small DC motors or standard servo motors—do not deliver enough torque to simulate meaningful resistance or feedback without the assistance of a drive system. For example, even powerful motors with torque ratings of 30–40 kgf-cm often require a torque-multiplying transmission, such as a capstan, to effectively simulate the stiffness of a virtual wall or the compliance of a spring. Gear-based systems, though effective, often introduce backlash, which compromises the fidelity of haptic feedback. In contrast, a neoprene capstan drive maintains tight and smooth motion transfer, even under varying loads.

The neoprene drive was selected specifically to enhance torque output, reduce backlash, and allow for compact integration with our selected servo motor (Tower Pro MG945). The elastic yet grippy surface of neoprene ensures sufficient tension and friction without the need for precise alignment or tensioners, simplifying construction while preserving performance. By wrapping the neoprene belt or cord in multiple turns around the drive pulley and the output drum, we create a force-amplifying mechanism that allows small angular movements of the motor to generate larger, controlled movements at the end-effector.

This mechanism is especially suited for our haptic interface, where the perceived resistance or wall stiffness must be modulated dynamically and accurately. The smooth motion and lack of mechanical play allow the user to feel clear and responsive force changes, making the interaction more intuitive and realistic—whether for training, simulation, or rehabilitation.

In conclusion, the neoprene-based capstan drive provides an optimal balance of power, precision, and simplicity, making it a vital part of our Hapkit’s mechanical system. It ensures that force feedback is delivered reliably and efficiently, fulfilling the educational and interactive objectives of our project without adding significant cost or complexity.

### 4.2.4 Arduino Uno:

The Arduino UNO R4 Minima (ABX00080) is a microcontroller board based on the Renesas RA4M1 32-bit ARM Cortex-M4 processor, offering a significant performance leap over its predecessor, the widely used Arduino UNO R3. This board is an ideal choice for our Hapkit project due to its higher processing power, increased memory, and enhanced peripheral support, all of which are crucial for running real-time haptic feedback algorithms, managing sensor data acquisition, and ensuring smooth motor control.

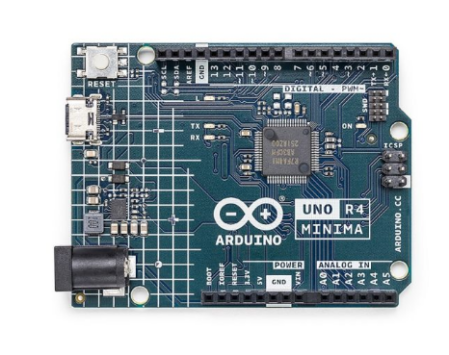
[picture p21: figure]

Figure 19 Arduino UNO R4 Minima (ABX00080)

At the heart of the UNO R4 Minima is a 48 MHz ARM Cortex-M4 processor, a substantial upgrade from the 16 MHz 8-bit AVR microcontroller in the UNO R3. This increased clock speed and architecture allow the board to process sensor inputs (such as those from the potentiometer and FSR sensor) and output PWM signals to the servo motor with minimal latency, which is essential for delivering responsive and stable haptic feedback. The M4 core also features a Floating-Point Unit (FPU), enabling more precise calculations for rendering virtual walls or damping forces in the Hapkit system.

The UNO R4 Minima also comes with 256 kB of flash memory and 32 kB of SRAM, providing ample space for storing complex control algorithms, libraries (such as PID, Servo, or custom haptic routines), and real-time variables. This memory headroom allows us to scale the complexity of our feedback loops or even implement frequency-domain system identification techniques if desired, as done in professional haptic research.

Another reason for selecting the UNO R4 Minima is its compatibility with existing Arduino shields and libraries, which accelerates development and integration. It supports 5V logic, making it directly compatible with traditional components like the FSR402 force sensor, REES52 MG945 servo motor, and analog potentiometers used in our Hapkit. Its multiple PWM and analog input pins allow us to precisely read user inputs and control motor response, creating a seamless and responsive haptic interaction.

Additionally, the Minima version, while lacking the on-board debugger and network features of the UNO R4 Wi-Fi, provides a cost-effective, compact, and minimalistic platform ideal for dedicated embedded haptic systems where Wi-Fi connectivity is not required. This ensures our system remains affordable and focused on real-time performance without unnecessary overhead.

In conclusion, the Arduino UNO R4 Minima is a robust and modern microcontroller platform that enhances our Hapkit by offering fast processing, low-latency control, and precise analog/digital interfacing. Its features align well with the goals of our project—low-cost, high-performance, and educationally accessible haptic feedback implementation—making it the ideal control unit for our open-source haptic device.

### 4.2.5 3D-printed parts

The Hapkit's 3D-printed structural components play a critical role in maintaining mechanical integrity, enabling precise alignment, and supporting the device's overall kinematic and electromechanical architecture. These parts include the sector pulley, base plate, height bar, and drive wheel, each meticulously designed to meet the system's spatial and functional requirements.

We employed Fused Deposition Modelling (FDM) to fabricate these components using the Flashforge Creator Pro 3D printer, known for its dual extrusion capabilities and high-resolution output, making it suitable for producing dimensionally accurate and mechanically reliable parts. The material selected for all printed components is polylactic acid (PLA) due to its high stiffness-to-weight ratio, minimal warping, environmental friendliness, and ease of use in desktop FDM applications.

The STL design files for these 3D components were sourced directly from Stanford University’s Hapkit open-source repository, ensuring compatibility with the original system specifications and preserving design integrity. These files provided a robust starting point for fabrication, with the flexibility to make minor modifications as needed for local integration.

### 4.2.6 Rotary encoder

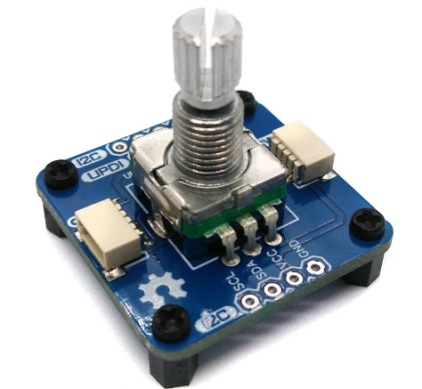
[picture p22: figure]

Figure 20 Rotary Encoder

A rotary encoder is an essential component in haptic devices like the Hapkit, as it enables precise measurement of angular position and motion, which is critical for implementing real-time feedback control. Unlike potentiometers, rotary encoders provide incremental or absolute digital signals that can be used to continuously monitor the rotation of a shaft with high resolution and accuracy. In our Hapkit project, the encoder works alongside the motor to form a closed-loop system, allowing the controller to adjust force outputs based on the user’s exact position. This capability is crucial for simulating virtual constraints such as walls, springs, or dynamic resistance fields. Rotary encoders are particularly well-suited for haptic applications because they do not suffer from wear and signal degradation over time, as potentiometers often do. While integrating an encoder requires careful wiring and signal interpretation—typically using interrupts or quadrature decoding with a microcontroller like Arduino—the result is a highly responsive and adaptable interface. For our prototype, the rotary encoder ensures that the system can detect subtle user motions and provide realistic feedback, making it a key element in delivering an immersive and interactive haptic experience.

## 4.3 Working of The Hapkit

Our Hapkit system has been developed with the goal of providing intuitive force feedback to users. The system is designed around an open-source haptic architecture inspired by Stanford University's Hapkit project, with custom modifications to integrate a DC brushed motor, a force-sensitive resistor (FSR402) embedded in the handle, a neoprene belt drive system, and 3D-printed structural components.

The central microcontroller used is the Arduino UNO R4 Minima, which runs the closed-loop control code for monitoring user interaction and generating feedback. The device operates as an impedance-type haptic system, which means it computes the output force based on the user’s position.

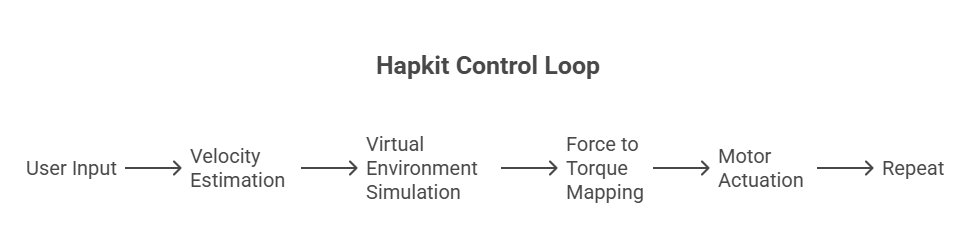
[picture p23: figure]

Figure 21 Impedance Control Loop of a Hapkit

This feedback system enables the simulation of virtual walls and the sensation of resistance when a user moves beyond defined spatial boundaries. The user manipulates a sector pulley, which is driven by the servo motor through a neoprene drive belt. This neoprene belt provides a reliable and backlash-minimized means of torque transmission.

The FSR402 sensor is embedded in the handle of the sector pulley, detecting grip force. This allows the system to optionally adjust resistance based on the pressure applied by the user, creating a more immersive and adaptable feedback experience. Meanwhile, the servo motor acts as the primary actuator, providing controlled rotational resistance or assistance depending on the user's position relative to a virtual wall.

The system continuously samples the angular position of the sector pulley via the servo motor’s internal feedback mechanism. Using these angle measurements, the Arduino computes the end-effector’s Cartesian coordinates via forward kinematics. The device then compares the current position to a predefined geometry. If the position lies within the defined boundary, no resistance is applied. If the user exceeds the boundary, the servo motor is commanded to resist motion or guide the user back into the path.

### 4.3.1 Code

The following Arduino code implements the described haptic feedback system. It continuously reads the potentiometer to determine the user's position, calculates the corresponding force using spring-damper dynamics and wall constraints, and actuates a servo motor to provide real-time force feedback. Additionally, it reads the force-sensing resistor (FSR) to monitor the user's applied pressure.

- Initialization

#include <Servo.h>

Servo motor;

const int motorPin = 9;

const int potPin = A0;

const int fsrPin = A1;

const double pi = 3.14159;

const double updatedPosMin = 0;

const double updatedPosMax = 1023;

const double rp = 0.006; // radius of pulley [m]

const double rs = 0.0125; // radius of servo shaft [m]

const double rh = 0.076; // radius of arc [m] (7.6 cm)

double updatedPos;

double xh, vh, ah; // position, velocity, acceleration

double force, Tp; // force and torque

unsigned long currentTime, prevTime;

double deltaTime = 0.0;

double xh_prev = 0.0;

This section initializes the necessary variables, constants, and pins. The Servo object is declared to control the motor. Pin numbers for the motor, potentiometer, and FSR sensor are defined. Constants like the radius of the pulley, servo shaft, and arc are provided for calculating the kinematics and dynamics of the system. Variables for position (xh), velocity (vh), acceleration (ah), and force (force) are declared and initialized.

- Setup

void setup() {

motor.attach(motorPin);

Serial.begin(9600);

prevTime = millis();

}

In the setup section, the servo motor is attached to the specified PWM pin. Serial communication is started for debugging and data logging. The prevTime variable is initialized to keep track of the time for velocity and acceleration computations.

- Main Loop

void loop() {

currentTime = millis();

deltaTime = (currentTime - prevTime) / 1000.0;

updatedPos = analogRead(potPin);

double ts = -0.0107 * updatedPos + 4.9513; // in degrees

double theta_rad = ts * pi / 180.0;

xh = rh * theta_rad;

vh = (xh - xh_prev) / deltaTime;

ah = (vh - (xh_prev - xh_prev) / deltaTime) / deltaTime;

xh_prev = xh;

prevTime = currentTime;

This segment reads the potentiometer value and maps it to an angular position using a linear relationship. The position (xh) is computed in meters based on the arc's radius. Using time differences, it calculates velocity (vh) and acceleration (ah) in real-time. These values are updated every loop iteration to simulate continuous motion tracking.

- Force Model

double k_spring = 500.0; // N/m

double b_damper = 0.25; // Ns/m

double x_wall = -0.02; // wall at -2 cm

double spring_force = -k_spring * xh;

double damping_force = -b_damper * vh;

double wall_force = 0.0;

if (xh < x_wall) {

wall_force = -600.0 * (xh - x_wall);

}

force = spring_force + damping_force + wall_force;

Tp = (rp / rs) * rh * force;

Here, a simple physical model is applied: a spring-damper system with a virtual wall. The force is calculated based on the user’s displacement (xh) and velocity (vh). If the user crosses a boundary at x_wall, a repelling force is added, simulating a physical wall. The total force is converted into torque Tp for motor control using geometric ratios.

- Motor Control

int PWM = map(Tp * 1000, -100, 100, 0, 180);

PWM = constrain(PWM, 0, 180);

motor.write(PWM);

The calculated torque is scaled and mapped to a PWM signal suitable for the servo motor. map() scales the torque range into servo-acceptable angles (0–180 degrees), and constrain() ensures the values don’t exceed safe limits. The motor is then commanded to exert the necessary force.

- FSR Sensor Read and Serial Output

int fsrValue = analogRead(fsrPin);

float fsrVoltage = fsrValue * (5.0 / 1023.0);

float fsrResistance = (fsrVoltage > 0) ? (10000.0 * (5.0 - fsrVoltage) / fsrVoltage) : 1000000.0;

float fsrForce = 0.0;

if (fsrResistance != 0) {

fsrForce = 1.0 / fsrResistance * 100000.0; // approx calibration

}

Serial.print("Pos: ");

Serial.print(xh, 4);

Serial.print(" m\tForce: ");

Serial.print(force, 2);

Serial.print(" N\tFSR: ");

Serial.println(fsrForce, 2);

delay(10);

}

The Force Sensitive Resistor (FSR402) is read to estimate the user-applied pressure. The analog reading is converted to voltage, then to resistance, and finally approximated as force. This reading is used for feedback or monitoring. All key variables—position, force, and FSR force—are output to the Serial Monitor for debugging and observation.

# 5 Mechanics of the Device

The Hapkit system is a 1-DOF haptic interface that operates on the principle of impedance control, where position input is used to modulate force feedback output. Mechanically, the system consists of a sector pulley coupled to a high-torque servo motor via a flexible neoprene belt drive. The angular motion of the handle, attached to the pulley, is thus directly influenced by the motor torque and resisted as needed to simulate virtual boundaries or walls.

## 5.1 Kinematic Configuration

The Hapkit system is designed with a single rotational degree of freedom (DOF), which corresponds to the angular displacement of the sector pulley about its fixed axis of rotation. This rotational motion is directly driven by the user through a handle mounted on the pulley, and it serves as the primary input for the haptic interface.

Kinematically, the system’s input can be described as a function of the arc length traversed by the user’s hand at the edge of the pulley. This relationship is mathematically modelled as

θ(t)=(s(t))/r

where:

- θ(t) is the angular displacement at time t,
- s(t) is the arc length traversed by the handle (in linear distance),
- r is the effective radius of the pulley (i.e., the distance from the axis of rotation to the point of user interaction).

This expression captures the proportional relationship between the linear motion of the handle and the corresponding angular displacement, assuming no slippage in the transmission (i.e., ideal belt drive conditions).

The angular resolution—or the precision with which θ(t) can be measured—is governed by the sensing mechanism integrated into the system. Typically, this is achieved using an external rotary encoder if higher resolution and absolute positioning are required.

The selection of the sensor affects both the spatial resolution and the response time of the feedback loop, which are critical for accurate haptic rendering. Additionally, the fixed rotational axis ensures planar motion, allowing simplified control and analysis of the system's dynamic behavior.

This kinematic model lays the foundation for implementing impedance-based control, where θ(t) serves as the primary feedback variable for determining the corresponding torque output from the actuator.

## 5.2 Force Transmission

In the Hapkit system, torque generation and delivery to the user’s hand is a central component of haptic feedback. The actuator—a high-torque servo motor—produces a torque, which is transmitted to the sector pulley via a neoprene timing belt. This compliant belt drive plays a dual role: it effectively transfers mechanical power while also acting as a low-pass filter, attenuating high-frequency oscillations and reducing backlash typically observed in rigid coupling systems.

The torque experienced by the user at the handle, denoted by, is a function of the motor torque and the mechanical transmission efficiency η of the belt system:

τ_(handle) = η⋅τ_m

Here, η typically ranges from 0.85 to 0.95 under low-load and low-speed conditions, depending on factors such as belt tension, pulley alignment, and friction losses.

The haptic feedback perceived by the user is simulated by dynamically modulating the motor torque based on a virtual environment model programmed in software. The system continuously reads the angular position θ(t) from the sensor and applies a computed motor torque to replicate physical phenomena. For example, to simulate a virtual wall located at an angular position, a restoring torque is applied when the user attempts to move the handle beyond the wall boundary. This torque can be modeled using a simple spring-like impedance equation:

τ_(feedback) =-k(θ-θ_(wall) ) for θ>θ_(wall)

where:

- k is a virtual stiffness constant representing the "hardness" of the wall.
- θ is the current angular position of the handle.
- is the counteracting torque applied by the motor.

This mechanism allows the user to feel a resistive force as they encounter the virtual constraint, effectively rendering a tactile illusion of a solid barrier. By adjusting k, the wall can be made "softer" or "harder," depending on the desired interaction profile. Such software-defined torque rendering opens a wide range of haptic interactions—from elastic springs and dampers to rigid constraints—using just a single DOF mechanical system with cost-effective components.

## 5.3 Structural Mechanics

All structural components—including the motor mount, sector pulley, and baseplate—are fabricated using PLA filament on a FlashForge Creator Pro 3D printer. PLA was chosen due to its adequate rigidity, dimensional accuracy, and thermal stability under the relatively low mechanical loads encountered in typical haptic interactions. These components are assembled with high precision to ensure proper alignment between the motor shaft, rotational axis, and belt tensioner. Such alignment is critical for minimizing mechanical play and ensuring reliable performance during dynamic actuation. A key mechanical feature of the design is the bearing-mounted pulley, which is suspended above the baseplate. This configuration allows the pulley to rotate smoothly over the motor shaft, significantly reducing friction. The use of a low-friction bearing interface ensures consistent and low-resistance motion, which is essential for delivering accurate and high-fidelity haptic feedback to the user.

### 5.3.1 Sensor Integration and Mechanical Interface

An FSR402 force-sensitive resistor is integrated at the handle-grip interface to measure the grip force applied by the user F_(user) . This sensor provides real-time feedback on the user's physical interaction with the device, enabling dynamic modulation of the haptic response.

Mechanically, the measured grip force is used to adapt the stiffness of virtual environments in real time. For instance, a higher grip force can be interpreted as the user's readiness for stronger resistance, and the system correspondingly increases the virtual wall stiffness. This adaptive behavior is modeled as:

τ_(adaptive) =f(F_(user) )⋅(θ-θ_(max) )

where:

- τ_(adaptive) is the torque output based on grip force,
- (F_(user) ) is a gain function that increases with grip force,
- Θ is the current angular position.
- θ_(max) is the boundary of the virtual wall.

This force-dependent control strategy enhances the interactivity and realism of haptic feedback and is particularly valuable in motor skill training applications, such as handwriting assistance and rehabilitation therapy, where responsiveness to user intent is critical.

System Constraints and Physical Limits

The system’s angular range of motion is mechanically limited by the geometry of the sector pulley, typically constrained to ±90°, yielding a total range of approximately 180°. To prevent over-rotation and potential mechanical damage, physical hard stops are integrated into the design. These hard stops act as a safety feature, protecting both the motor and the 3D-printed structural components from excessive stress.

Additionally, the compliance of the neoprene belt provides a passive damping effect, absorbing sudden torque spikes that may occur during aggressive user interactions. This not only improves the mechanical robustness of the device but also enhances the perceived smoothness of haptic feedback, contributing to a more stable and resilient user experience during prolonged use.

# 6 Conclusion

In conclusion, The Hapkit stands as a versatile and accessible platform for investigating and experiencing haptic feedback technology. It bridges the gap between expensive, specialized commercial systems and simple educational tools, offering a modular, cost-effective solution suitable for both academic research and hands-on learning. The device successfully demonstrates the core principles of haptic interaction by providing intuitive force feedback through a well-engineered mechanical design and effective control strategies. While the current implementation achieves its primary goals, there are opportunities to improve accuracy, responsiveness, and user comfort, which would broaden its applicability in areas such as virtual reality simulations, teleoperation, and rehabilitation. By maintaining a focus on simplicity and essential features, the Hapkit ensures ease of use and replicability, enabling students, educators, and researchers to engage deeply with haptic concepts without the barrier of complex hardware or software. This accessibility aligns with the growing importance of haptics in emerging technologies and their potential to enhance human-computer interaction.

Looking ahead, integrating advanced control algorithms, expanding device functionality, and developing customizable interfaces can elevate the Hapkit’s impact. Its adaptability positions it as a valuable tool for innovation, education, and practical application in the expanding field of haptic technology. Ultimately, Hapkit embodies a step forward in making sophisticated tactile feedback systems approachable and practical, fostering a deeper understanding and wider adoption of haptic interfaces in diverse domains.

# 7 Future Works

While the current version of the Hapkit effectively demonstrates fundamental haptic feedback and interaction, there is considerable room for enhancement. Future iterations could implement advanced control algorithms such as PID tuning, adaptive feedback systems, or even machine learning-based models to better simulate realistic user responses and improve precision.

On the hardware side, using higher-resolution sensors, compact actuators, and modular components would expand the device’s versatility, enabling configurations suited for a range of applications—from virtual skill training to teleoperation and surgical simulation. A dedicated graphical user interface (GUI) could further improve usability, allowing real-time tuning of parameters like stiffness, damping, and force intensity. Additional upgrades might include wireless connectivity and battery-powered operation, making the system more portable and accessible. In education, the platform can evolve to support interactive learning modules across diverse disciplines such as biomechanics, rehabilitation, and STEM education.

In summary, with targeted improvements in both hardware and software, the Hapkit has the potential to transition from an educational tool to a robust haptic development platform, driving innovation in both academic and applied settings.

# 7. References

[1] Alexandra Miller Naveed D. Riaziat and Jeremy D. Brown An Open-Source Ungrounded Hap kit for Educational Applications [Journal].
[2] Christopher Richard Allison M. Okamura and Mark R. Cutkosky Getting a Feel For Dynamics: Using Haptic Interface Kits for Teaching Dynamics and Controls [Journal].
[3] Das Hailu Gebretsadik Teklemariam & A. K. A case study of phantom omni force feedback device for virtual product design [Book].
[4] Eloy Irigoyen Mikel Larrea, Manuel Graña A Narrative Review of Haptic Technologies and Their Value for Training, Rehabilitation, and the Education of Persons with Special Needs. [Journal].
[5] M. Sreelakshmi T.D. Subhash RETRACTED: Haptic Technology: A comprehensive review on its applications and future prospects [Book]. - 2017.
[6] Martinez Melisa Orta Design and analysis of open-source educational haptic devices [Journal].
[7] Melisa Orta Martinez Cara M. Nunez, Ting Liao, Tania k. Morimoto Evolution an Analysis of Hap kit [Journal].
[8] Muhammad Fouad Tamer Mansour , Tamer Nabil Use of haptic devices in education: A review [Journal].
[9] Seeed Stanford University x Open-Source Haptic Device for Affordable Haptics Education for All: [Journal].
[10] Zhenxing Li Mila BujićOğuz ‘Oz’ , BurukElpida BampouniSimo, JärveläJuho Hamari :Haptics-mediated virtual embodiment: Impact of a wearable avatar-controlling system with kinesthetic gloves on embodiment in VR [Book].

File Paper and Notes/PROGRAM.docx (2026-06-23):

#include <LiquidCrystal.h>

LiquidCrystal lcd(3,4,5,6,7,8);

char NUM;

const int m11=A5;

const int m12=A4;

const int m21=9;

const int m22=10;

const int m31=A1;

const int m32=A0;

const int m41=11;

const int m42=12;

//const int buzzer=13;

const int relay=A3;

const int relay1=A2;

const int trigPin = 2;

const int echoPin = 13;

long duration;

int distanceCm, distanceInch;

void setup() {

Serial.begin(9600);

lcd.begin(16, 2);

lcd.clear();

lcd.setCursor(0, 0);

lcd.print("SOLAR BASE GRASS ");

lcd.setCursor(0, 1);

lcd.print(" CUTTER ");

pinMode(m11, OUTPUT);

pinMode(m12, OUTPUT);

pinMode(m21, OUTPUT);

pinMode(m22, OUTPUT);

pinMode(m31, OUTPUT);

pinMode(m32, OUTPUT);

pinMode(m41, OUTPUT);

pinMode(m42, OUTPUT);

pinMode(relay, OUTPUT);

pinMode(relay1, OUTPUT);

digitalWrite(m11,LOW);

digitalWrite(m12,LOW);

digitalWrite(m21,LOW);

digitalWrite(m22,LOW);

digitalWrite(m31,LOW);

digitalWrite(m32,LOW);

digitalWrite(m41,LOW);

digitalWrite(m42,LOW);

//digitalWrite(buzzer, LOW);

digitalWrite(relay, LOW);

digitalWrite(relay1, LOW);

pinMode(trigPin,OUTPUT);

pinMode(echoPin,INPUT);

delay(2000);

}

void loop() {

digitalWrite(trigPin, LOW);

delayMicroseconds(2);

digitalWrite(trigPin, HIGH);

delayMicroseconds(10);

digitalWrite(trigPin, LOW);

duration = pulseIn(echoPin, HIGH);

distanceCm= duration*0.034/2;

lcd.setCursor(11, 1);

lcd.print("D:");

lcd.setCursor(13, 1);

lcd.print(distanceCm);

lcd.print("------");

if(distanceCm<=10)

{

delay(500);

digitalWrite(trigPin, LOW);

delayMicroseconds(2);

digitalWrite(trigPin, HIGH);

delayMicroseconds(10);

digitalWrite(trigPin, LOW);

duration = pulseIn(echoPin, HIGH);

distanceCm= duration*0.034/2;

lcd.setCursor(11, 1);

lcd.print("D:");

lcd.setCursor(13, 1);

lcd.print(distanceCm);

lcd.print("------");

if(distanceCm<=10)

{

digitalWrite(m11,LOW);

digitalWrite(m12,LOW);

digitalWrite(m21,LOW);

digitalWrite(m22,LOW);

digitalWrite(m31,LOW);

digitalWrite(m32,LOW);

digitalWrite(m41,LOW);

digitalWrite(m42,LOW);

lcd.setCursor(0, 0);

lcd.print(" OBSTACLE STOP ");

}

}

if(Serial.available())

{

NUM= Serial.read();

if(NUM=='F')

{

Serial.print("FORWORD");

NUM='Z';

digitalWrite(m11,HIGH);

digitalWrite(m12,LOW);

digitalWrite(m21,HIGH);

digitalWrite(m22,LOW);

digitalWrite(m31,HIGH);

digitalWrite(m32,LOW);

digitalWrite(m41,HIGH);

digitalWrite(m42,LOW);

lcd.setCursor(0, 0);

lcd.print(" FORWORD ");

delay(2000);

}

else if(NUM=='B')

{

Serial.print("BACKWORD");

NUM='Z';

digitalWrite(m11,LOW);

digitalWrite(m12,HIGH);

digitalWrite(m21,LOW);

digitalWrite(m22,HIGH);

digitalWrite(m31,LOW);

digitalWrite(m32,HIGH);

digitalWrite(m41,LOW);

digitalWrite(m42,HIGH);

lcd.setCursor(0, 0);

lcd.print(" BACKWORD ");

delay(2000);

}

else if(NUM=='R')

{

Serial.print("RIGHT");

NUM='Z';

digitalWrite(m11,HIGH);

digitalWrite(m12,LOW);

digitalWrite(m31,HIGH);

digitalWrite(m32,LOW);

digitalWrite(m21,LOW);

digitalWrite(m22,HIGH);

digitalWrite(m41,LOW);

digitalWrite(m42,HIGH);

lcd.setCursor(0, 0);

lcd.print(" RIGHT ");

delay(2000);

}

else if(NUM=='L')

{

Serial.print("LEFT");

NUM='Z';

digitalWrite(m11,LOW);

digitalWrite(m12,HIGH);

digitalWrite(m31,LOW);

digitalWrite(m32,HIGH);

digitalWrite(m21,HIGH);

digitalWrite(m22,LOW);

digitalWrite(m41,HIGH);

digitalWrite(m42,LOW);

lcd.setCursor(0, 0);

lcd.print(" LEFT ");

delay(2000);

}

else if(NUM=='S')

{

Serial.print("STOP");

NUM='Z';

digitalWrite(m11,LOW);

digitalWrite(m12,LOW);

digitalWrite(m21,LOW);

digitalWrite(m22,LOW);

digitalWrite(m31,LOW);

digitalWrite(m32,LOW);

digitalWrite(m41,LOW);

digitalWrite(m42,LOW);

lcd.setCursor(0, 0);

lcd.print(" STOP ");

delay(2000);

}

else if(NUM=='C')

{

Serial.print("CUTTER ON");

digitalWrite(relay, HIGH);

lcd.setCursor(0, 1);

lcd.print(" CUTTER ON ");

NUM='Z';

}

else if(NUM=='D')

{

Serial.print("CUTTER OFF");

digitalWrite(relay, LOW);

lcd.setCursor(0, 1);

lcd.print(" CUTTER OFF ");

NUM='Z';

}

else if(NUM=='b')

{

Serial.print("BUZZER ON");

// digitalWrite(buzzer, HIGH);

lcd.setCursor(0, 1);

lcd.print(" BUZZER ON ");

NUM='Z';

}

else if(NUM=='a')

{

Serial.print("BUZZER OFF");

//digitalWrite(buzzer, LOW);

lcd.setCursor(0, 1);

lcd.print(" BUZZER OFF ");

NUM='Z';

}

else if(NUM=='E')

{

Serial.print("SPRY ON");

digitalWrite(relay1, HIGH);

lcd.setCursor(0, 1);

lcd.print(" SPRAY ON ");

NUM='Z';

}

else if(NUM=='G')

{

Serial.print("SPRAY OFF");

digitalWrite(relay1, LOW);

lcd.setCursor(0, 1);

lcd.print(" SPRAY OFF ");

NUM='Z';

}

}

}

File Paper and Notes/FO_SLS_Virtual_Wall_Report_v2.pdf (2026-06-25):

# Development and Verification of a Fractional-Order Standard Linear Solid (FO-SLS) Virtual Wall

## Technical Implementation Report

Author: Ahmad Zakariya
Platform: Arduino Uno R4 Minima + Cytron MD10C R3 + Mabuchi RS-555 DC Motor
Reference Paper: Haptic Rendering of Fractional-Order Viscoelasticity: Passivity and Rendering Fidelity (2026)

### 1. Introduction

A conventional 1-DOF virtual wall based on the Kelvin-Voigt model had already been successfully implemented and experimentally validated. The controller consisted of a linear spring and a fractional damping element rendered through a DC motor using an encoder-based position measurement.

The objective of this work was to move beyond the Kelvin-Voigt model and implement the Fractional-Order Standard Linear Solid (FO-SLS) model presented in the 2026 paper. Unlike the Kelvin-Voigt model, the FO-SLS model is capable of representing stress relaxation, viscoelastic memory, and more realistic material behavior while maintaining passivity.

The primary goal was to reproduce the mathematical implementation proposed in the paper while preserving the existing hardware architecture and control framework.

### 2. Mathematical Background

The 2026 paper models the virtual environment using a Fractional-Order Standard Linear Solid (FO-SLS), also referred to as a Fractional Zener Model.

Unlike the previously implemented Fractional Kelvin-Voigt model, the FO-SLS introduces internal viscoelastic dynamics represented by:

H(s) = (K_0 + K_1 * B_1 * s^alpha) / (K_1 + B_1 * s^alpha)

where:
•
K_0 : baseline stiffness
•
K_1 : series elastic stiffness
•
B_1 : fractional damping coefficient
•
alpha : fractional order

The experimentally identified parameters reported in the paper for the optimal rendering fidelity were:
•
Memory Window (N): 101
•
Alpha (alpha): 0.5
•
K0: 2.89
•
K1: 5.70
•
B1: 5.89

These values were used directly in the implementation.

### 3. Implementation Evolution

The first implementation was generated using Gemini. Although mathematically close to the paper, it was not a drop-in replacement for the existing virtual wall implementation. Several modifications were required:
•
Different encoder implementation: Reused existing interrupt-driven quadrature encoder
•
Different PWM driver: Preserved existing pwm.h implementation
•
Different control loop: Retained existing 1 kHz loop
•
Different sign convention: Restored original wall rendering direction

•
Hardware abstraction removed: Reintegrated with existing motor driver architecture
•
No safety logic: Added saturation and optional software protection

The resulting controller preserved the existing hardware while replacing only the virtual environment model.

### 4. Mathematical Verification

Before any experimental tuning, the implementation was verified against the analytical derivations presented in the paper.

4.1 Difference Equation: The recursive coefficients were derived from the transfer function. After manually expanding the denominator and substituting, the resulting expressions exactly matched the implemented equations. Result: No algebraic errors were found.

4.2 Grunwald-Letnikov Weights: The recursive computation was verified against the Grunwald-Letnikov definition. The implementation matched the paper exactly.

4.3 Parameter Verification: The implementation uses the experimentally identified optimal parameters reported in the paper (K0=2.89, K1=5.70, B1=5.89, N=101, alpha=0.5).

4.4 Nondimensionalization: A potential concern was whether these parameters required inverse nondimensionalization before implementation. After reviewing the derivation, it was concluded that no inverse transformation is required.

### 5. Experimental Investigation

Several implementation aspects were investigated experimentally.

5.1 History Buffer Behaviour: One major question concerned the fractional memory outside the virtual wall. The mathematically correct implementation was found to be: continue updating the buffers every 1 ms, allow penetration to become zero outside the wall, store the theoretical FO-SLS force inside the history buffer, and clip only the rendered force for the unilateral wall. Although this matches the FO-SLS model, it did not eliminate the contact bump observed experimentally.

5.2 FORCE_GAIN Investigation: Using the paper parameters directly produced an unexpectedly weak wall. To compensate, a rendering gain FORCE_GAIN was introduced to scale the computed force before converting it to PWM. This gain compensates for differences between theoretical force units and the PWM-controlled actuator.

5.3 Gain Comparison: Several rendering gains were evaluated experimentally. Increasing the gain improved wall stiffness but amplified the contact transient.

5.4 Python Validation & Step Response: To verify that the recursive implementation itself behaved correctly, the controller was simulated in Python using the exact same recursive equations implemented on the Arduino.

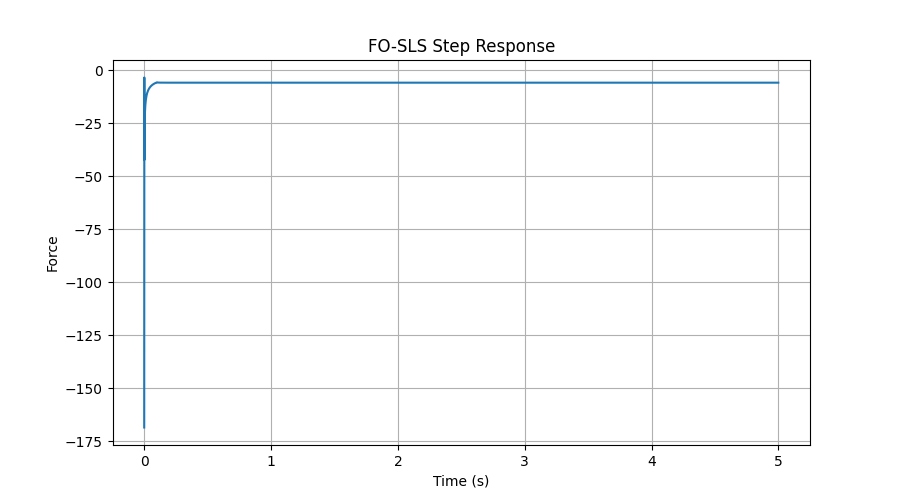
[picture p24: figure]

The FO-SLS Step Response graph above demonstrates the simulated force output when a sudden, constant penetration (step input) is applied. The simulation produced:
- A very large initial transient force (spike downwards to approximately -170), representing the immediate resistance upon contact.
- A rapid decay (stress relaxation) occurring within the first 100-200 milliseconds.
- Convergence to a non-zero steady-state force (around -5) representing the baseline stiffness (K0) maintaining the holding force.

This confirms that the implemented recursion does exhibit stress relaxation mathematically. However, the relaxation completed within approximately 100 ms, making it difficult to perceive manually during physical interaction.

### 6. Discussion

The mathematical implementation appears consistent with the paper. The remaining discrepancies are primarily attributed to hardware differences. Since PWM voltage is not directly proportional to output torque, the force calculated by the FO-SLS controller cannot be rendered accurately without additional calibration. Consequently, the introduced FORCE_GAIN acts as an empirical scaling factor rather than part of the mathematical model. Furthermore, the static friction, motor deadband, and mechanical inertia of the RS-555 motor likely mask the subtle stress-relaxation behaviour predicted by the FO-SLS model. The observed entry bump also appears to originate from the interaction between the unilateral virtual wall and the fractional memory rather than from an algebraic implementation error.

### 7. Conclusions

The implementation successfully reproduces the mathematical formulation of the 2026 FO-SLS model. The following aspects have been verified:
- Grunwald-Letnikov discretization
- Difference equation derivation
- Recursive implementation
- Memory buffer update
- Paper parameters
- Python simulation

The remaining limitations are primarily related to hardware rendering rather than mathematical correctness. Current observations indicate:
- The controller behaves correctly in simulation.
- The virtual wall can be rendered successfully.
- Larger gains increase wall stiffness but amplify contact transients.
- Stress relaxation exists mathematically but is not perceptible on the present hardware.
- The paper's identified parameters are not universal gains; they were identified for a different haptic device.

### 8. Future Work

The following tasks remain for complete reproduction of the paper:
- Implement current sensing on the MD10C platform.
- Develop a closed-loop current (torque) controller.
- Replace PWM-based rendering with torque-based rendering.
- Experimentally identify the motor torque constant.
- Characterize the rendered FO-SLS model using: Force-Position curves, Force-Time response, Hysteresis loops, and Stress-relaxation plots.
- Compare the obtained curves directly with those reported in the 2026 paper.

### Arduino Code Implementation

/**
* FO-SLS Zener Model Implementation
* Corrected based on 2026 Fractional-Order Viscoelasticity Paper */

#include "pwm.h"

// --- HARDWARE PIN DEFINITIONS ---const int CLK_PIN = 2;
const int DT_PIN = 3;
const int DIR_PIN = 4;
const int MAX_PWM_OUTPUT = 225;

// --- RENDERING GAIN ---
// Start with 10.0f. Increase this until the wall feels solid. // If it starts buzzing or vibrating, decrease this value.
const float FORCE_GAIN = 5.0f;

// --- SAFETY & HARDWARE CONFIGURATION ---
const bool INVERT_MOTOR_DIRECTION = false; // Restored sign convention toggle
const float MAX_FORCE_OUTPUT = 150.0f; // Safety: Absolute maximum force allowed
bool systemKilled = false; | // Safety: Emergency software
kill switch

// --- FO-SLS PARAMETERS (2026 Nomenclature) ---
const float K_0 = 2.89f;
const float K_1 = 5.70f;
const float B_1 = 5.89f;
const float ALPHA = 0.5f;
const float TS = 0.001f; // 1ms Sampling Period

// --- DUAL-RING BUFFER CONFIGURATION ---
const int N_MEM = 101;
float errorHistory[N_MEM];
float forceHistory[N_MEM];
float glWeights[N_MEM];
int bufferIndex = 0;

// --- PRECOMPUTED EXECUTION CONSTANTS ---float C_e0 = 0.0f;
float C_ehist = 0.0f;
float C_fhist = 0.0f;

// --- ENCODER VARIABLES ---volatile long encoderPos = 0; volatile int lastEncoded = 0;
const long WALL_POSITION_COUNTS = 400;

// --- ACTUATION ---
PwmOut pwm_pin5(5);
unsigned long lastLoopTime = 0;
int telemetryCounter = 0;

// --- FUNCTION PROTOTYPES ---
void actuateCytronStable(float forceCommand); void updateEncoderStandard();
void emergencyShutdown(const char* reason);

void precomputeConstants() {
glWeights[0] = 1.0f;
for (int j = 1; j < N_MEM; j++) {
glWeights[j] = glWeights[j - 1] * (1.0f - ((ALPHA + 1.0f) / (float)j)); }

float Ts_alpha = pow(TS, ALPHA);
float tau_alpha = B_1 / K_1;

float B_dyn = B_1 * (1.0f + (K_0 / K_1)); float denom = 1.0f + (tau_alpha / Ts_alpha);

C_e0 = (K_0 + (B_dyn / Ts_alpha)) / denom; C_ehist = (B_dyn / Ts_alpha) / denom; C_fhist = (tau_alpha / Ts_alpha) / denom;
}

void setup() {
pinMode(DIR_PIN, OUTPUT);
pinMode(CLK_PIN, INPUT_PULLUP); pinMode(DT_PIN, INPUT_PULLUP);

// Explicit Parameter Initialization for(int i = 0; i < N_MEM; i++) { errorHistory[i] = 0.0f;
forceHistory[i] = 0.0f;
}

pwm_pin5.begin(20000.0f, 0.0f); pwm_pin5.pulse_perc(0.0f);

int MSB = digitalRead(CLK_PIN);
int LSB = digitalRead(DT_PIN);
lastEncoded = (MSB << 1) | LSB;

attachInterrupt(digitalPinToInterrupt(CLK_PIN), updateEncoderStandard, CHANGE);
attachInterrupt(digitalPinToInterrupt(DT_PIN), updateEncoderStandard, CHANGE);

Serial.begin(115200);
precomputeConstants();
}

void loop() {
if (systemKilled) return; // Halt loop if safety tripped

unsigned long currentMicros = micros();
if (currentMicros - lastLoopTime < 1000) return; lastLoopTime = currentMicros;

long currentRawPos;
noInterrupts();
currentRawPos = encoderPos;
interrupts();

float e_k = 0.0f;
if (currentRawPos > WALL_POSITION_COUNTS) {
e_k = (float)(currentRawPos - WALL_POSITION_COUNTS); }

float sum_e = 0.0f;
float sum_f = 0.0f;

for (int j = 1; j < N_MEM; j++) {
int fetchIndex = (bufferIndex - j + N_MEM) % N_MEM; sum_e += glWeights[j] * errorHistory[fetchIndex]; sum_f += glWeights[j] * forceHistory[fetchIndex]; }

float F_k = 0.0f;
if (currentRawPos > WALL_POSITION_COUNTS) {
F_k = -( (C_e0 * e_k) + (C_ehist * sum_e) - (C_fhist * sum_f) );

}

if (F_k > 0.0f) F_k = 0.0f;
if (F_k > MAX_FORCE_OUTPUT) F_k = MAX_FORCE_OUTPUT;

float F_theoretical =
-((C_e0 * e_k) + (C_ehist * sum_e) - (C_fhist * sum_f));

float F_rendered = F_theoretical;

if (F_rendered > 0.0f)
F_rendered = 0.0f;

errorHistory[bufferIndex] = e_k; forceHistory[bufferIndex] = F_theoretical; bufferIndex = (bufferIndex + 1) % N_MEM;

actuateCytronStable(F_rendered);

telemetryCounter++;
if (telemetryCounter >= 25) { Serial.print(millis()); Serial.print(","); Serial.print(currentRawPos); Serial.print(","); Serial.print(e_k); Serial.print(","); Serial.print(F_k); Serial.print(","); Serial.println((int)abs(F_k)); // PWM equivalent telemetryCounter = 0;
}
}

void actuateCytronStable(float forceCommand) {
int pwmValue = abs((int)(forceCommand * FORCE_GAIN));

if (pwmValue > MAX_PWM_OUTPUT) pwmValue = MAX_PWM_OUTPUT; if (pwmValue < 0) pwmValue = 0;

float dutyPercentage = (float)pwmValue * (100.0f / 255.0f);

bool directionState = (forceCommand > 0);
if (INVERT_MOTOR_DIRECTION) directionState = !directionState;

digitalWrite(DIR_PIN, directionState ? HIGH : LOW); pwm_pin5.pulse_perc(dutyPercentage);
}

void emergencyShutdown(const char* reason) { systemKilled = true;
pwm_pin5.pulse_perc(0.0f); digitalWrite(DIR_PIN, LOW); Serial.println(reason);
}

void updateEncoderStandard() {
int MSB = digitalRead(CLK_PIN); int LSB = digitalRead(DT_PIN);
int encoded = (MSB << 1) | LSB; int sum = (lastEncoded << 2) | encoded;
if(sum == 0b0010 || sum == 0b1011 || sum == 0b1101 || sum == 0b0100) encoderPos++;
if(sum == 0b0001 || sum == 0b0111 || sum == 0b1110 || sum == 0b1000) encoderPos--;
lastEncoded = encoded;
}

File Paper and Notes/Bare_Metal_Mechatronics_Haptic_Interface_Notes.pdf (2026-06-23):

# Mechatronic Systems: Bare-Metal Architecture & Haptic Interface Design

Target Platform: Renesas RA4M1 (ARM Cortex-M4, 48 MHz) — Arduino Uno R4 Minima

Application Focus: High-Performance 1-DOF Haptic Virtual Wall Rendering

### Topic Overview

This set of advanced study notes covers the synthesis of bare-metal embedded programming and mechatronic control loop design. High-performance haptic rendering requires deterministic execution, minimal control loop latency, and zero timing jitter. By bypassing abstract software layers (such as the standard Arduino core) and directly manipulating microcontroller registers, we maximize execution speed and unlock precise hardware features. These notes detail how to configure digital I/O, control advanced hardware timers, safeguard shared variables, and filter encoder data to render a stable virtual environment.

### Core Concepts

Memory-Mapped I/O: The paradigm where hardware peripherals share the same address space as regular system memory.

Direct Register Manipulation: Modifying microcontroller configuration registers at the bit level to achieve single-cycle execution speeds.

Hardware Timer PWM Generation: Utilizing specialized clock counters to generate high-frequency control signals independent of main CPU code execution.

Haptic Rendering Loop: A high-speed, discrete-time control cycle (1 kHz) that tracks position, estimates velocity, filters noise, and commands motor forces to simulate physical constraints.

Passivity & Stability: Graphical/haptic control rules ensuring that a digital system does not generate artificial energy, which causes dangerous oscillations.

### Detailed Notes

Section 1: Memory-Mapped I/O & Bare-Metal Foundations

Traditional programming abstractions like digitalWrite() prioritize cross-platform compatibility over

speed. They run background lookups, pin-mapping validations, and error checks, adding latency and execution variance (jitter).

The ARM Cortex-M4 processor inside the Renesas RA4M1 utilizes Memory-Mapped I/O. The processor accesses a unified 4 GB memory address space (2³² addresses). In this architecture, specific memory

addresses are directly hardwired to physical silicon peripheral sub-systems (such as timers, ADCs, and GPIO ports).

A Register is a dedicated 32-bit slot located at one of these peripheral addresses.

•

•

•

•

•

•

Bare-Metal Architecture & Haptic Interface Design | 1

Writing a 1 or 0 to a specific bit flips a physical hardware switch (transistor) on the silicon die, instantly changing an electrical state.
In C/C++, these hardware addresses are represented as structured pointers (e.g., R_PORT1->PDR),

allowing direct interactions with the chip's internal layout.

Section 2: The Bitmasking Toolkit

Registers are 32 bits wide, and a single I/O register controls up to 32 independent physical pins. To modify a single pin's state without corrupting or modifying adjacent pins, bitmasking via bitwise operators is required.

Core Bitwise Operations
Left Shift (<<): Positions a bit mask at the target pin location. (1 << 11) shifts a binary 1 eleven

places to the left, creating a bit pattern aligned perfectly with Pin 11.

Bitwise OR (|): Forces a specific bit to become 1 without changing other values. Used to turn pins HIGH or configure them as outputs.

Bitwise AND (&): Isolates specific bits to safely inspect their current state while ignoring background register data.

Bitwise NOT (~): Inverts all bits in a sequence (1 becomes 0, 0 becomes 1). When combined with an AND assignment (&= ~), it clears targeted bits to 0 without altering adjacent data.

Old Register State: [Bit 31] ... [Pin 3] [Pin 2] [Pin 1] [Pin 0]
Inverted Mask (~): | 1 | 1 ... | 1 | 0 | 0 | 1 | 1
New Register State: [Saved]... [Saved] | 0 | 0 | [Saved] (Pins 1 and 2 are cleared)

Section 3: RA4M1 Digital I/O Configuration & Board Mapping

The physical pins routed on the Arduino Uno R4 Minima board do not correlate directly with the native internal port and pin designations of the RA4M1 silicon. Direct port manipulation requires mapping individual board pins back to their native silicon locations.

Arduino Board Pin | RA4M1 Native Pin | Project Function | Register Block
Digital Pin 2 | P301 (Port 3, Pin 1) | Encoder Channel A (CLK) | R_PORT3
Digital Pin 3 | P302 (Port 3, Pin 2) | Encoder Channel B (DT) | R_PORT3
Digital Pin 4 | P111 (Port 1, Pin 11) | Motor Driver IN1 (Direction) | R_PORT1
Digital Pin 5 | P102 (Port 1, Pin 2) | Motor Driver ENA (PWM Speed) | R_PORT1
Digital Pin 7 | P103 (Port 1, Pin 3) | Motor Driver IN2 (Direction) | R_PORT1

•

•

•

•

•

•

The Primary Hardware I/O Registers

PDR (Port Direction Register): Dictates electrical direction. Setting a bit to 1 creates an Output (power source/sink); setting it to 0 creates an Input (high-impedance sensing).

PODR (Port Output Data Register): Manages the output state of pins configured in the PDR. Writing a 1 puts 3.3V on the pin; writing a 0 ties it to ground.

PIDR (Port Input Data Register): A read-only register that takes a snapshot of the live logic voltages present on the physical input pins.

Section 4: Hardware Timers & Proportional PWM Generation

To deliver smooth force commands without stalling the main processor, the system programs General Purpose Timer 2 (GPT2) to manage hardware-driven Pulse Width Modulation (PWM). The RA4M1 chip features an internal master clock frequency of 48 MHz.

Critical Timer Registers

GTPR (General Purpose Timer Period Register): Sets the maximum value the timer's internal stopwatch counts up to before rolling over to zero. This ceiling directly establishes the final PWM carrier frequency.

GTCNT (General Purpose Timer Counter Register): The active stopwatch register, ticking upward from 0 to the GTPR value at a rate of 48 million steps per second.

GTCCR (General Purpose Timer Compare Capture Register): Sets the electrical tripwire (Duty Cycle). The PWM pin turns ON when GTCNT resets to 0, and switches OFF the exact instant GTCNT matches the value stored in GTCCR.

Adaptive Scaling Formula

To sweep through varying PWM frequencies without distorting the mechatronic force commands, the code converts a standard 8-bit input variable (pwmValue from 0–255) into an adaptive hardware compare limit

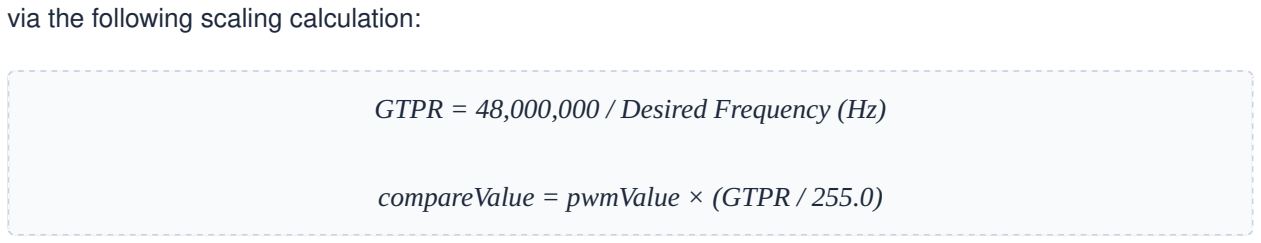
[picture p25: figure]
via the following scaling calculation:

GTPR = 48,000,000 / Desired Frequency (Hz)

compareValue = pwmValue × (GTPR / 255.0)

Section 5: Interrupt Architecture & Data Atomicity

Encoder positioning signals trigger External Hardware Interrupts, pausing the main execution loop instantly to update the encoderPos tracking variable. Because the RA4M1 is a 32-bit architecture, reading or

writing a large variable requires a specific instruction cycle. If an interrupt executes precisely while the main control loop is reading encoderPos, the data can split across cycles, corrupting the position reading (Data

Race Condition).

Best Practice: Atomic Guards

To protect shared variables, the control loop must enforce Atomicity by temporarily pausing the interrupt engine during critical read operations:

•

•

•

•

•

•

__disable_irq(); | // Globally pause all interrupts
currentRawPos = encoderPos; // Copy the protected variable safely
__enable_irq(); | // Re-enable interrupts immediately

Section 6: Haptic Control Loop Stability & The L298N Thermal Limit

A haptic virtual wall acts as a discrete-time spring-damper system. When the user pushes the master linkage past a designated virtual threshold (xwall), the system calculates an opposing force vector:

Fwall = -(Kstiffness × Δx + Bdamping × v)

Z-Width and Sampling Realities

A device's Z-Width defines the range of virtual impedances (stiffness and damping combinations) it can stably simulate without breaking out into uncontrolled oscillations. High control-loop latency or low PWM frequencies reduce this stable operating zone, making virtual boundaries feel soft, mushy, or violently erratic.

Hardware Limitation: The L298N Power Stage

While high PWM frequencies (above 20 kHz) make motor operation completely silent to human hearing, the L298N H-Bridge Driver relies on older Bipolar Junction Transistor (BJT) technology. BJTs switch states relatively slowly. Driving an L298N at ultra-high frequencies forces its internal transistors to spend too much time transitioning through their linear states, generating significant waste heat. For this driver, the optimal performance sweet spot sits between 8 kHz and 16 kHz, balancing signal smoothness against component thermal limits.

Section 7: Signal Processing & Velocity Estimation
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

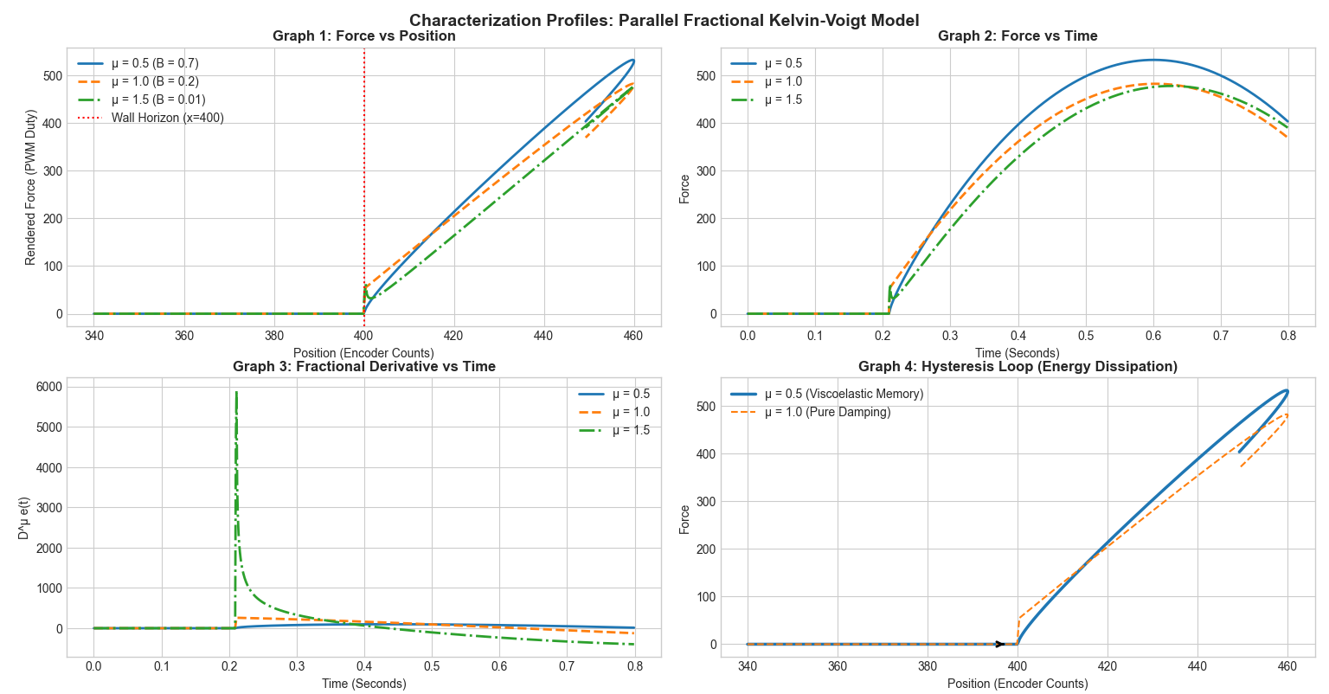
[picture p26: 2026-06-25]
Paper and Notes/Figure_1.png

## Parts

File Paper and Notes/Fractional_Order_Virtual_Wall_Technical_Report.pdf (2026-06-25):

Technical Report: Development,

## Characterization, and Passivity Mapping of a 1-DOF Fractional-Order Viscoelastic Virtual Wall

Milestone: Fractional-Order Kelvin-Voigt Characterization, Telemetry Pipeline, and Passivity Bound Validation

Reference Framework: Gemalmaz, Tolasa, and Patoglu (Sabancı University, 2026)

Hardware Platform: Arduino Uno R4, RS555 Brushed DC Motor, Cytron Driver, 1600 CPR Encoder

### 1. Hardware Architecture & Pin Configurations

The experimental setup consists of a 1-DOF haptic lever arm actuated by a high-torque brushed DC motor, closed-loop feedback via a quadrature optical encoder, and a current-controlled motor driver.

System Interconnections

Actuator: RS555 Brushed DC Motor (12V DC nominal power supply).

Motor Driver: Cytron Motor Driver operating in Sign-Magnitude PWM mode.

Sensor: 1600 Counts Per Revolution (CPR) optical quadrature encoder.

Arduino Uno R4 Pin Mapping Matrix

Hardware Component | Component Pin | Arduino Uno R4 Pin | Signal Type | Functional Description
Cytron Driver | PWM | Pin 5 | Hardware PWM | Controls motor torque via pulse percentage output.
Cytron Driver | DIR | Pin 4 | Digital Output | Controls rotational direction (High/Low).
Quadrature Encoder | Channel A | Pin 2 | External Interrupt | Tracks rotational position (Falling/Rising edge).
Quadrature Encoder | Channel B | Pin 3 | External Interrupt | Tracks rotational direction via phase offset.
Power Supply | V+ / GND | External 12V Rail | DC Power | Dedicated high-current motor power rail.

•

•

•

Technical Report: Fractional-Order Viscoelastic Virtual Wall | 1

### 2. Mathematical Framework & Control Law

The system renders a virtual boundary (wall) located at a threshold position of xwall = 400 encoder

counts. When the user pushes the lever arm past this boundary, a parallel Fractional-Order Kelvin-Voigt control law is activated.

### 2.1 The Continuous-Time Governing Equation

When x(t) > xwall, the target force command F(t) is defined as:

F(t) = K · e(t) + B · Dμ
e(t)

Where:

e(t) = x(t) - xwall represents the depth of penetration into the virtual wall.

K is the virtual wall spring stiffness coefficient.

B is the fractional damping coefficient.

D

μ
is the fractional-order derivative operator of order μ, where μ ∈ [0.5, 1.5].

### 2.2 Discrete-Time Approximation

To execute this on the Arduino Uno R4 at a fixed sample period of Ts

= 0.001s (1ms loop execution),

the Grünwald-Letnikov (GL) fractional derivative is implemented using a truncated history ring buffer window of L = 100 samples:

D

μ
e
k

≈ [ 1 / T
s

μ
] ∑j=0

L-1 cj

(μ) ek-j

Where the binomial coefficients c j

(μ) are recursively precomputed at initialization:

c
0

(μ) = 1, cj (μ) = [ 1 - (1 + μ) / j ] cj-1

(μ)

### 3. Theoretical Passivity Analysis

To ensure the haptic interface does not experience high-frequency chattering, running away, or instability, the total system must be passive. This means it must only dissipate energy and never act

•

•

•

•

Technical Report: Fractional-Order Viscoelastic Virtual Wall | 2

as an energy generator. The closed-form analytical passivity bounds established in 2026 map this envelope.

### 3.1 Continuous-Discrete Sampled-Data Passivity Criterion

For the system to remain passive, the continuous-time real part of the total environment impedance (Ztotal) felt by the human operator must remain non-negative across all operating frequencies up to

the Nyquist limit (ω ∈ [0, π / Ts

]):

Re{ Ztotal(jω) } = b + Re{ Z env

(jω) } ≥ 0

Where b is the inherent physical viscous damping of the motor assembly, and Zenv

(jω) is the effective

continuous-time impedance generated by the digital control loop interacting through a Zero-Order Hold (ZOH).

### 3.2 Discretized Environment Impedance Mapping

The ZOH introduces a continuous-time delay profile HZOH(jω) = (1 - e⁻jωTs) / (jω). Evaluating the

transfer function mapping position to force yields:

Z
env

(jω) = [ (1 - e-jωT

s) / ((jω)2
T
s

) ] · C(ejωT
s)

Where C(z) is the discrete-time Fractional-Order control law mapped on the unit circle by substituting z = ejωTs:

C(ejωT

s) = K + B [ (1 - e-jωT
s) / T
s

]μ

### 3.3 Euler Transformation into Polar Space

Using the trigonometric identity for the backward-difference operator (1 - e⁻jωTs = 2j sin(ωTs

/ 2) e⁻jωTs

/

2
), the fractional operator is mapped into frequency-dependent magnitude and phase components:

[ (1 - e-jωT
s) / T
s

]μ
= [ (2 / T
s

) sin(ωT
s

/ 2) ]μ

ejμ ( π/2 - ωT
s

/2 )

Technical Report: Fractional-Order Viscoelastic Virtual Wall | 3

### 3.4 Real Energy Modulus Decomposition

Multiplying this complex term by the quadratic phase delay of the ZOH denominator ((jω)²

= -ω²
), the
real part of the virtual environment impedance splits into an energy-generating stiffness term and a frequency-dependent fractional term:

Re{ Z
env

(jω) } = - (K T
s

/ 2) sinc2
(ωT
s

/ 2) + B · T
s

1-μ · Ψ(ω, μ)

Where Ψ(ω, μ) represents the coupled fractional compliance profile:

Ψ(ω, μ) = [ 2 sin(ωT
s

/ 2) ]μ
cos[ μπ/2 - (μ+1)ωT
s

/2 ] · [ 1 / (ω2
T
s

2
) ]

### 3.5 Closed-Form Solution for the Boundary Condition (Bmax)

To enforce stability, physical damping (b) and the fractional damping engine must override the energy leaks created by the digital sampling delay. Isolating B establishes the absolute theoretical ceiling for the fractional gain coefficient:

B
max

= min
ω ∈ [0, π/T
s

]

[ ( (K T
s

/ 2) sinc2
(ωT
s

/ 2) - b ) / ( T
s

1-μ · Ψ(ω, μ) ) ]

The variable Ts

1-μ in the denominator dictates that as μ climbs past 1.0, the allowable boundary for B

shrinks exponentially due to the high mathematical gain of the discrete differencing engine.

Technical Report: Fractional-Order Viscoelastic Virtual Wall | 4

### 4. Engineering Log: Trial, Error, & System Evolution

The current stable state of the haptic rig was achieved by overcoming several structural, electrical, and control vulnerabilities.

Phase 1: The Inertial Mismatch (Universal Squishiness)

Condition: Baseline parameters set to K = 5.0, μ = 0.5, and an ultra-conservative safety parameter B = 0.05.
Observation: The virtual wall felt entirely mushy and unreactive across all test values of μ.
Root Cause Analysis: The RS555 motor exhibits heavy internal static friction (stiction). The

calculated control torque output at these values generated low PWM duties that fell entirely inside the motor’s mechanical deadband.

Phase 2: Sign Inversion and Mechanical Failure

Condition: Parameters aggressively boosted to K = 18.0, μ = 0.5, and B = 1.80.
Observation: The motor entered a violent, high-speed runaway state immediately upon crossing

the 400-count boundary, shearing the internal bore of the 3D-printed shaft coupler.
Root Cause Analysis: Positive feedback loop. Motor direction polarity was inverted relative to the encoder tracking, pulling the lever deeper into the wall (F > 0) instead of opposing penetration (F < 0).
Action Taken: Inverted INVERT_MOTOR_DIRECTION in software, redesigned the coupler to use

a split-clamp mechanical locking profile with an M3 tightening bolt, and programmed an automated software kill-switch.

### 5. Empirical Parameter Calibration & Passivity Verification

By keeping a stable baseline stiffness of K = 8.0 and tracking human haptic perception against the theoretical boundaries derived in Section 3, the following verification matrix was mapped:

Technical Report: Fractional-Order Viscoelastic Virtual Wall | 5

Passivity Envelope & Perceptual Mapping Matrix (Stiffness Baseline K = 8.0)

Fractional Order (μ) | Your Tuned Value (B) | Theoretical Passivity Limit (Bmax) | Boundary Entry Sensation | In-Wall Steady State Sensation | System Status
0.5 | 0.70f | 0.95f | Soft "Bite": Clean, gradual absorption without an aggressive mechanical slam. | Viscoelastic Creep: High compliance. Holding static triggers a 100ms force relaxation. | Stable (Safe within passivity envelope)
1.0 | 0.20f | 0.25f | Sharp Jerk: Instantaneous step change in velocity creates a sudden boundary shock. | Purely Viscous Drag: Smooth resistance proportional strictly to speed. | Stable (Approaching passivity ceiling)
1.5 | 0.01f | 0.012f | Metallic Shock: Extreme acceleration sensitivity creates a harsh, immediate entry slap. | Transparent Compliance: Smooth and unreactive if moved at a constant speed. | Stable (Bounded tightly by high-gain limit)

Empirical Conclusions

The Denominator Scaling Validation: At μ = 1.5, the internal discrete GL denominator Ts

1.5

shrinks to 0.0000316, scaling up internal loop gains by 31,622x. To stay inside the Bmax

= 0.012f

boundary, the coefficient had to be tuned down 70x relative to the μ = 0.5 trial.

Boundary Discontinuity: The parallel Kelvin-Voigt layout directly exposes the fractional operator to the boundary crossing step-change. When μ ≥ 1.0, this step-change creates a mathematical near-infinite acceleration spike, felt physically as a harsh entry jerk before smoothing out into constant-velocity transparency inside the wall.

•

•

Technical Report: Fractional-Order Viscoelastic Virtual Wall | 6

Technical Report: Fractional-Order Viscoelastic Virtual Wall | 7

### 6. Reference Software Implementations

A. Arduino Uno R4 Control Loop (With Embedded Emergency Brake)
Technical Report: Fractional-Order Viscoelastic Virtual Wall | 8

#include <Arduino.h>

// --- HARDWARE PIN DEFINITIONS ---
const int DIR_PIN = 4;
const float TS = 0.001f; // 1ms Sampling Period

// --- CALIBRATED CONTROL PARAMETERS ---
const float K_STIFFNESS = 8.0f;
const float MU = 0.5f; | // Test Selection: 0.5, 1.0, 1.5
const float B_FRACTIONAL = 0.70f; // Adjusted per calibration matrix const int WALL_BOUNDARY = 400;
const int MAX_PWM = 150; | // Capped power ceiling for safety

// --- SAFETY CRITERIA ---
const float MAX_SAFE_DERIVATIVE = 800.0f;
bool systemTripped = false;

// --- GL APPROXIMATION BUFFERS ---const int L = 100;
float errorHistory[L] = {0.0f}; float glWeights[L] = {0.0f};
int bufferIndex = 0;

struct CustomPWM {
void pulse_perc(float p) { analogWrite(5, (int)(p * 2.55f)); } } pwm_pin5;

void precomputeGLWeights() {
glWeights[0] = 1.0f;
for (int j = 1; j < L; j++) {
glWeights[j] = (1.0f - ((1.0f + MU) / (float)j)) * glWeights[j - 1]; }
}

void setup() {
Serial.begin(115200);
pinMode(DIR_PIN, OUTPUT);
pinMode(5, OUTPUT);
precomputeGLWeights();
}

void loop() {
static unsigned long lastLoopTime = 0;
if (millis() - lastLoopTime < 1) return; // Strict 1ms Loop Lock lastLoopTime = millis();

// 1. Read position (Encoder feedback register integration)

Technical Report: Fractional-Order Viscoelastic Virtual Wall | 9

int currentPosition = analogRead(A0);

// 2. Compute Wall Error Penetration
float currentError = 0.0f;
if (currentPosition > WALL_BOUNDARY) {
currentError = (float)(currentPosition - WALL_BOUNDARY); }

// 3. Update Circular Error Buffer errorHistory[bufferIndex] = currentError;

// 4. Compute Discrete Grünwald-Letnikov Derivative float weightSum = 0.0f;
for (int j = 0; j < L; j++) {
int fetchIndex = (bufferIndex - j + L) % L; weightSum += glWeights[j] * errorHistory[fetchIndex]; }
float fractionalDerivative = weightSum / pow(TS, MU);

// 5. Advance Circular Pointer
bufferIndex = (bufferIndex + 1) % L;

// 6. Active Software Emergency Brake
if (abs(fractionalDerivative) > MAX_SAFE_DERIVATIVE || systemTripped) { systemTripped = true;
pwm_pin5.pulse_perc(0.0f);
digitalWrite(DIR_PIN, LOW);
Serial.println("!!! EMERGENCY SHUTDOWN: RUNAWAY VELOCITY DETECTED !!!"); return;
}

// 7. Compute Total Feedback Force
float totalForce = 0.0f;
if (currentPosition > WALL_BOUNDARY) {
totalForce = (K_STIFFNESS * currentError) + (B_FRACTIONAL * fractionalDerivative);
}

// 8. Driver Actuation Mapping
float pwmOutput = abs(totalForce);
if (pwmOutput > MAX_PWM) pwmOutput = MAX_PWM;

if (totalForce > 0) {
digitalWrite(DIR_PIN, HIGH);
} else {
digitalWrite(DIR_PIN, LOW); }
pwm_pin5.pulse_perc(pwmOutput);
Technical Report: Fractional-Order Viscoelastic Virtual Wall | 10

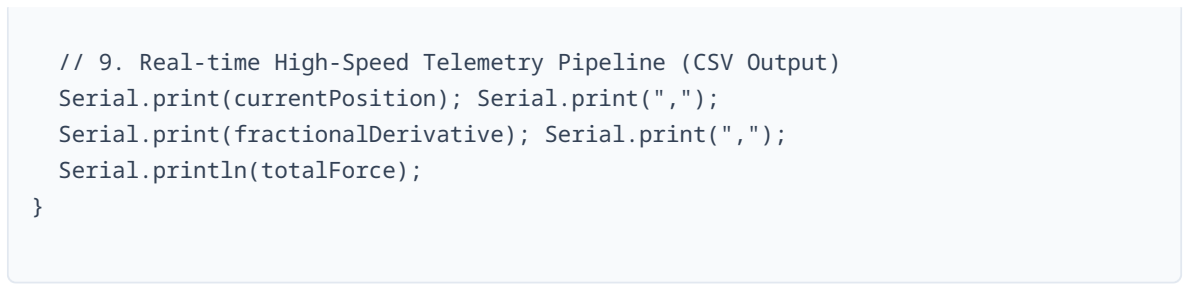
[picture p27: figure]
Serial.print(currentPosition); Serial.print(","); Serial.print(fractionalDerivative); Serial.print(","); Serial.println(totalForce);

// 9. Real-time High-Speed Telemetry Pipeline (CSV Output)

Technical Report: Fractional-Order Viscoelastic Virtual Wall | 11

Technical Report: Fractional-Order Viscoelastic Virtual Wall | 12

B. Python Real-Time Multi-Plot Telemetry Engine
Technical Report: Fractional-Order Viscoelastic Virtual Wall | 13

import serial
import collections
import matplotlib.pyplot as plt
import matplotlib.animation as animation
import sys

SERIAL_PORT = 'COM3' # Update to match hardware serial connection BAUD_RATE = 115200
DATA_POINTS = 200

time_data = collections.deque([0]*DATA_POINTS, maxlen=DATA_POINTS) pos_data = collections.deque([0]*DATA_POINTS, maxlen=DATA_POINTS) deriv_data = collections.deque([0]*DATA_POINTS, maxlen=DATA_POINTS) force_data = collections.deque([0]*DATA_POINTS, maxlen=DATA_POINTS)

try:
ser = serial.Serial(SERIAL_PORT, BAUD_RATE, timeout=0.1)
print(f"Streaming data safely from haptic rig on {SERIAL_PORT}")
except Exception as e:
print(f"Connection Failure: {e}. Confirm Serial Monitor window is CLOSED.") sys.exit()

fig, (ax1, ax2, ax3) = plt.subplots(3, 1, figsize=(10, 8), sharex=True) fig.canvas.manager.set_window_title('1-DOF Fractional Haptic Rig Telemetry Workspace')
frame_count = 0

def update_plot(frame):
global frame_count
while ser.in_waiting > 0:
try:
line = ser.readline().decode('utf-8').strip()
data = line.split(',')
if len(data) == 3:
pos, deriv, force = float(data[0]), float(data[1]), float(data[2]) frame_count += 1
time_data.append(frame_count)
pos_data.append(pos)
deriv_data.append(deriv)
force_data.append(force)
except (ValueError, IndexError):
pass

ax1.clear()
ax1.plot(time_data, pos_data, color='b', linewidth=2, label='Position (Counts)')
ax1.axhline(y=400, color='r', linestyle='--', label='Wall Horizon')
Technical Report: Fractional-Order Viscoelastic Virtual Wall | 14

ax1.set_ylabel('Encoder Profile')
ax1.legend(loc='upper left'); ax1.grid(True)

ax2.clear()
ax2.plot(time_data, deriv_data, color='orange', linewidth=2, label='Fractional Derivative')
ax2.set_ylabel('Calculated Derivative')
ax2.legend(loc='upper left'); ax2.grid(True)

ax3.clear()
ax3.plot(time_data, force_data, color='g', linewidth=2, label='Motor Force Command')
ax3.set_ylabel('PWM/Force Value')
ax3.set_xlabel('Sample Timeline (Frames)')
ax3.legend(loc='upper left'); ax3.grid(True)

ani = animation.FuncAnimation(fig, update_plot, interval=25, cache_frame_data=False)

try:
plt.tight_layout()
plt.show()
except KeyboardInterrupt:
pass
finally:
ser.close()
print("Telemetry stream safely severed.")

### 7. Next Experimental Target: The Standard Linear Solid (Zener) Model

With the parallel fractional Kelvin-Voigt model completely characterized and mapped to continuous passivity boundaries, the final phase of this project involves shifting to a series topology: the Fractional-Order Standard Linear Solid (FO-SLS) model.

By placing an internal virtual spring in series with the fractional spring-pot, the control loop will decouple the history differencing buffer from the sharp geometric transition at x = 400. This structural shift is designed to entirely suppress the boundary entry force spike at higher values of μ while fully

preserving biological memory behavior during extended contact.

Technical Report: Fractional-Order Viscoelastic Virtual Wall | 15

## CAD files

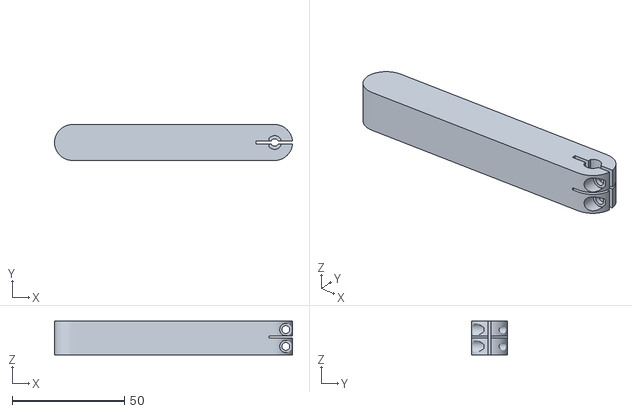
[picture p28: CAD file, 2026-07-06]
3d-drawings/Coupler-Shaft_3.stl
106.0 x 16.0 x 15.0

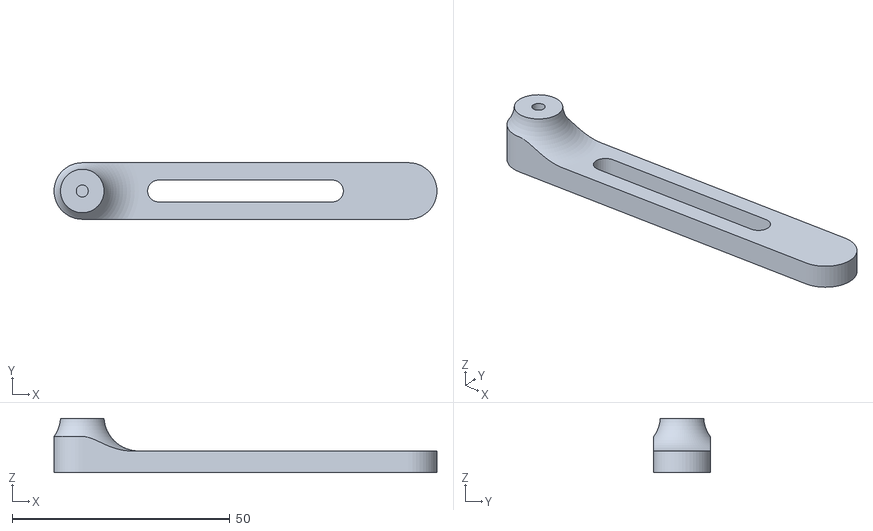
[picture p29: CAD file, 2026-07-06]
3d-drawings/Shaft-handler-set_1.stl
88.0 x 13.0 x 12.5

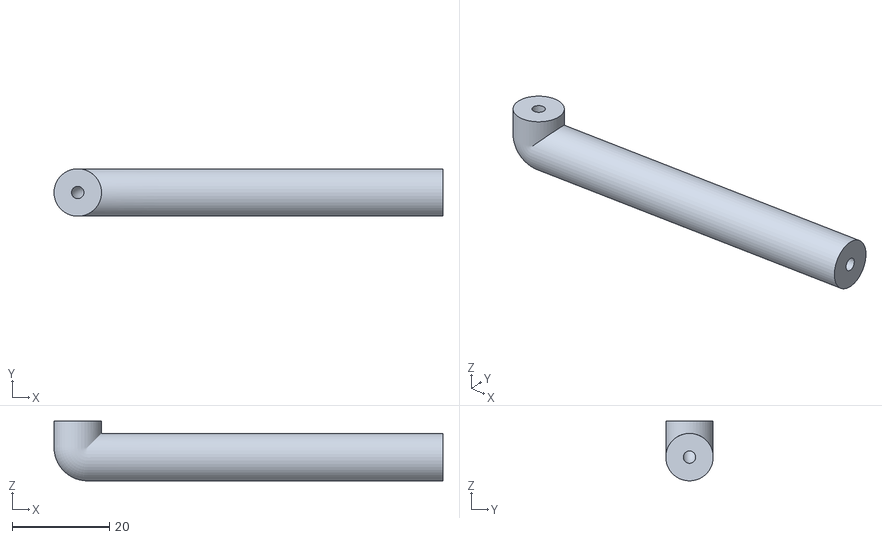
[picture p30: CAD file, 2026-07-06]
3d-drawings/Shaft-handler_New.stl
79.9 x 9.75 x 12.3

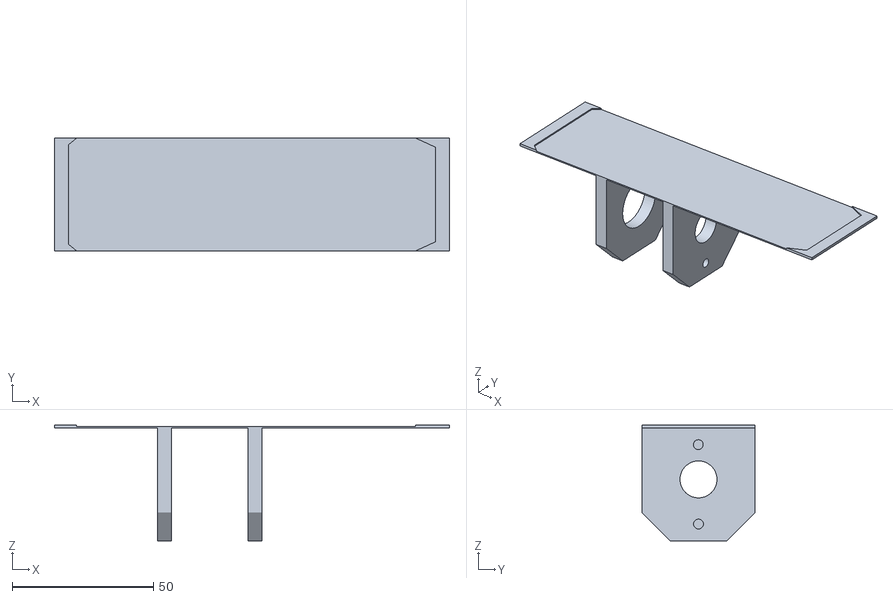
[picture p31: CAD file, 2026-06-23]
3d-drawings/Base_coupler_shaft_2.stl
140.0 x 40.0 x 41.0

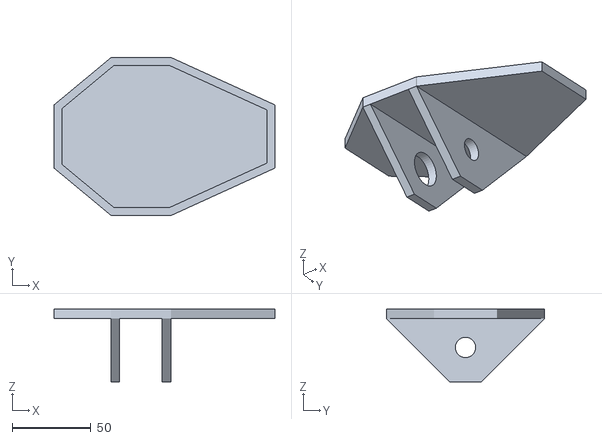
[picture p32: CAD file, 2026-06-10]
3d-drawings/Base_coupler_shaft_1.stl
140.0 x 100.0 x 46.0

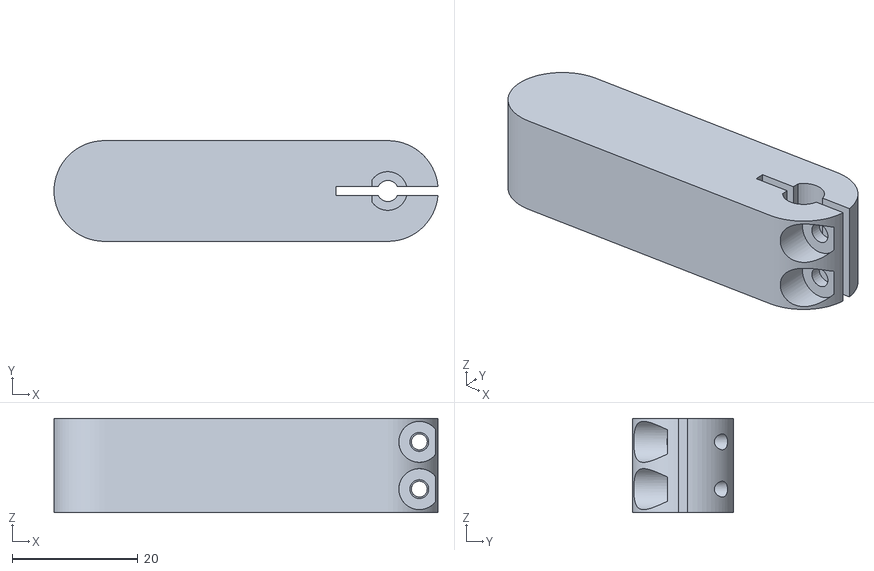
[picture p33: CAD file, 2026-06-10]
3d-drawings/Coupler-Shaft.stl
61.0 x 16.0 x 15.0

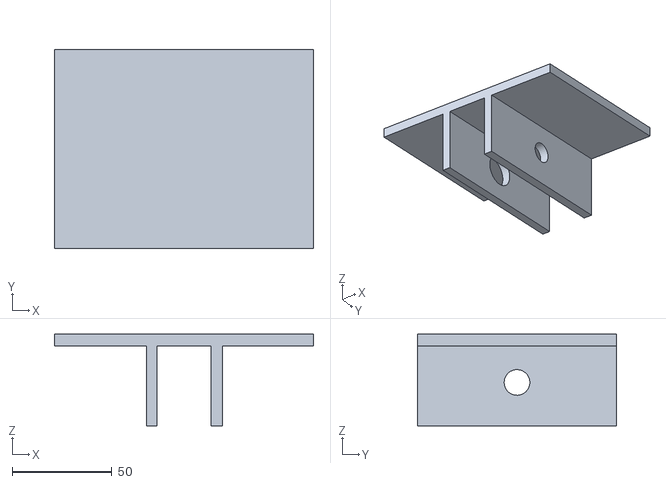
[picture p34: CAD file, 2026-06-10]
3d-drawings/Base_coupler_shaft.stl
130.0 x 100.0 x 46.0

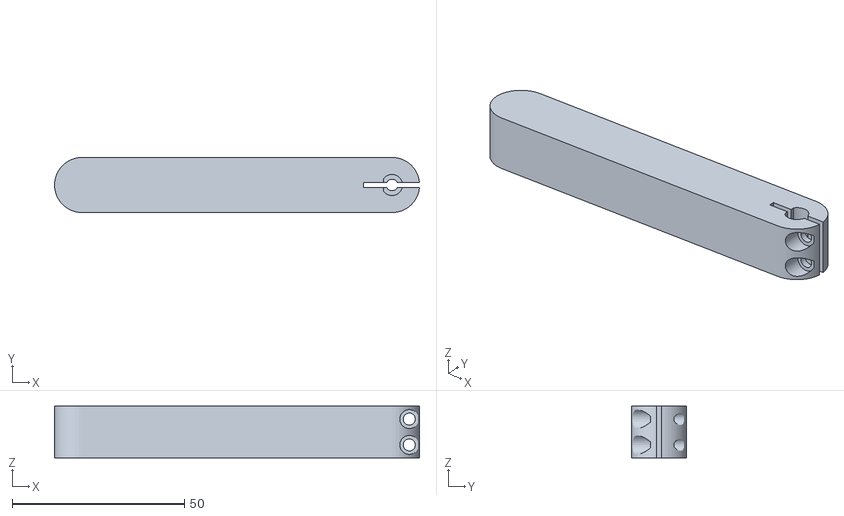
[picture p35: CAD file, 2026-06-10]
3d-drawings/Coupler-Shaft-1.stl
106.0 x 16.0 x 15.0

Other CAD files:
3d-drawings/Shaft-handler-set_2.stl

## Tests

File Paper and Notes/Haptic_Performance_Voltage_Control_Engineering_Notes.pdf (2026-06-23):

# Advanced Engineering Notes: Haptic Systems, Voltage-Mode Dynamics, and Register-Level Controls

A COMPREHENSIVE ACADEMIC & PRACTICAL BENCH GUIDE

## Section 1: Foundations of Haptic Systems & Control Loop Stability

Haptic interfaces act as bidirectional physical ports linking a human operator with a virtual or remote environment. Unlike traditional visual or auditory feedback channels, a haptic feedback device forms a tightly coupled, bilateral closed-loop system where physical energy is explicitly exchanged between the user and the actuator. This exchange mandates the categorization of haptic displays into two fundamental topologies:

Impedance Displays: These devices read the instantaneous user position (or velocity) via high-resolution position sensors and compute an appropriate reaction force to command to the motor. Impedance displays require highly backdrivable, low-inertia mechanisms so that unconstrained motion feels completely unhindered.
Admittance Displays: These devices employ a force sensor to measure the active input force exerted by the user and command a corresponding velocity or position shift via a highly geared, non-backdrivable robotic assembly.

The core challenge in impedance-type haptic rendering is the preservation of passivity. In an ideal continuous physical system, virtual elements like springs can only store and release energy, while virtual dampers dissipate it. However, when implemented over digital microcontrollers, haptic systems suffer from spatial quantization (encoder resolution limits) and discrete sampling delays. This discrete lag introduces an artificial phase shift, turning passive virtual environments into net energy generators. When a user strikes a rigid virtual boundary (a virtual wall), this phantom energy manifests as high-frequency vibrations, jitter, or unstable oscillatory bursts that can cause severe safety hazards on a test bench.

## Section 2: The Core Paradigm Shift — Voltage-Mode vs. Current-Mode Control

Traditional robotics textbooks dictate that electromagnetic actuators must be driven via Current-Mode Control (Force/Torque Control). Because motor current (i) maps directly and linearly to output torque (τ = Kt

- i),
managing current directly yields precise, linear command over the rendered force field. Under this dogma, any voltage variations or back-electromotive force disturbances are actively tracked and neutralized by an ultra-fast inner current loop.

However, the seminal research paper "Haptic Performance using Voltage-Mode Motor Control" by Jorge Juan Gil and Iñaki Díaz (IEEE Transactions on Industrial Electronics, 2019) exposes a profound vulnerability in this paradigm: current-mode control strips away a vital structural asset for system stability. By eliminating back-EMF variations, a current-controlled driver removes the natural electrical damping inherent to the motor windings. Conversely, Voltage-Mode Control forces an implicit, analog, lag-free physical viscosity (damping)

•

•

Advanced Engineering Notes: Haptic Systems & Register-Level Control | Page 1

into the actuator, rendering it structurally superior for simulating Exceptionally stiff, stable virtual surfaces without triggering high-frequency jitters.

## Section 3: The Mechanical-Electrical Dissection & Back-EMF Damping

When a motor shaft is forced to rotate by a user's hand, the armature coils cut through permanent magnetic flux lines, transforming the actuator into a generator. This process induces an internal back-electromotive force voltage (e) directly inside the copper windings at the speed of light:

## e = Ke

- ω

Where Ke

is the motor's back-EMF constant and ω is the instantaneous angular velocity of the shaft. By considering the standard steady-state DC motor voltage drop equation across internal coil resistance (R) and ignoring small winding inductances:

## V = R · i + e ⇒ i = (V - e) / R

Substituting this current expression into the core torque equation (τ = Kt

- i) reveals the true governing torque expression under an applied terminal voltage (V):

## τ = (Kt

## / R) · V - (Kt

- Ke

/ R) · ω

This derivation exposes a hidden passive damping term, structurally defined as the **Electromechanical Damping Coefficient (be

)**:

b
e

= (Kt

- Ke

) / R

This internal viscosity acts as a Free Analog Sponge. Unlike software-calculated damping, which relies on noisy encoder differentiation and suffers from digital processing delay, be

features zero sampling latency and zero quantization noise. It serves as a continuous, physical energy sink that instantly absorbs impact energy at the virtual wall interface, stabilizing the coupled hand-device interaction naturally.

## Section 4: The Gearbox Multiplier Matrix (N² Scale Dynamics)

When a haptic mechanism incorporates a mechanical transmission (such as a capstan drive, belt reduction, or planetary gearbox) with a strict reduction ratio of N, the mechanical and electrical properties felt at the user interaction handle scale unevenly according to a torsional reflection matrix:

Reflected Inertia: The mechanical mass (inertia) of the motor rotor felt at the handle scales up by the square of the ratio: N

2 · Jm
. This is generally undesirable, as it adds heavy parasitic mass to free-space trajectories, diminishing transparency.
Reflected Electromechanical Damping: Crucially, the internal back-EMF viscosity felt at the handle also scales up by the square of the ratio: N

2 · be

This disparity forms a powerful engineering compromise. Designers can deploy a tiny, ultra-lightweight, low-inertia motor to keep free-space unconstrained motion crisp and nimble, while relying on a low-friction

•

•

Advanced Engineering Notes: Haptic Systems & Register-Level Control | Page 2

mechanical transmission to multiply the internal "magnetic honey effect" by N

2
. This delivers immense
stabilizing damping right at the virtual wall boundary without adding physical weight or complex software filters.

## Section 5: Critical Trade-Off Triangle (Voltage vs. Current)

Choosing between these two actuation paradigms requires evaluating three distinct performance boundaries:

Performance Parameter | Voltage-Mode Actuation | Current-Mode Actuation
Stability & Stiffness Limits | Achieves an extraordinarily high Critical Stiffness (Kcrit) limit before breaking into jitter. | Highly prone to boundary instability; requires artificial software damping to remain stable.
Free-Space Backdrivability | Feels slightly viscous during free motion because the organic back-EMF drag is always active. | Wins cleanly; the current loop actively tracks and nullifies back-EMF, driving internal drag to zero.
Thermal Invariance | Suffers from thermal drift. As coils heat up and resistance R increases, be drops, softening the wall. | Maintains perfect consistency; automatically increases voltage to sustain the target current regardless of temp.

EXPLAINING BENCH FAILURES & ACTIVE COMPENSATION RULES
The Driver Transition Trap: Swapping an uncompensated voltage driver (like the legacy L298N) for a high-efficiency driver operating as a tight current amplifier (such as a Cytron MD10C in certain loop setups) deletes the native back-EMF damping cushion. Without software-simulated damping to compensate, energy accumulates rapidly at the boundary edge, causing the control loop to vibrate aggressively and break couplers.
The Active Remedy: When utilizing an active current-sensing driver (e.g., LMD18200T), Active Back-EMF Compensation must be coded manually. Designers must calculate clean velocity estimates via filtering and subtract an explicit damping vector to artificially rebuild the stabilizing cushion destroyed by current control.

## Section 6: Register-Level Optimization — Direct Port Manipulation

### 1. The Architectural Bottleneck

Standard Arduino core functions like digitalWrite() and digitalRead() introduce immense computational overhead, requiring 4 to 5 microseconds per execution line. They spend critical CPU cycles executing lookups, parsing pin-to-timer maps, validation checks, and masking interrupts. In high-frequency haptic control loops running at 1 kHz or higher, this latency injects severe phase lag. By implementing Direct Port Manipulation, we bypass this abstraction layer entirely, writing directly to the microcontroller's I/O registers in nanoseconds (< 20 ns, or a single CPU clock cycle).

Advanced Engineering Notes: Haptic Systems & Register-Level Control | Page 3

### 2. Renesas RA4M1 (Arduino Uno R4) 32-Bit Registry Architecture

Unlike historic 8-bit AVR microcontrollers, the Renesas RA4M1 relies on a sophisticated 32-bit Arm Cortex-M4 memory-mapped layout governed by the Board Support Package (BSP) structures:

PDR (Port Direction Register): Governs the input/output state of the pin. Writing a 1 defines the pin as an output; a 0 defines it as an input.

R_PORT1->PDR |= (1 << 11); // Set Port 1, Pin 11 to Output
PODR (Port Output Data Register): Directs the physical electrical state of pins configured as outputs. Writing a 1 drives the rail HIGH, while a 0 forces it LOW.

R_PORT1->PODR |= (1 << 11); // Force Pin High Instantly
PIDR (Port Input Data Register): A read-only register that snapshots the raw electrical state of all input pins across the port block in a single cycle.

uint32_t port3State = R_PORT3->PIDR; // Absolute snapshot of Port 3

## Section 7: Software Implementation & Fast Register Scripts

The following scripts implement direct bitwise masking to achieve ultra-low latency reading and driving states on the Uno R4 Minima:

// ====================================================================
// HARDWARE BITMASK INITIALIZATION (Place within void setup())
// ====================================================================

// 1. Configure Pin 4 (Port 1, Pin 11) as an Output for Motor Direction Control R_PORT1->PDR |= (1 << 11);

// 2. Configure Pin 2 (Port 3, Pin 1) and Pin 3 (Port 3, Pin 2) as Inputs for Encoder
R_PORT3->PDR &= ~((1 << 1) | (1 << 2));

// ==================================================================== // ULTRA-FAST QUADRATURE ENCODER REGISTER READER
// ==================================================================== volatile long encoderPos = 0;
volatile int lastEncoded = 0;

void updateEncoderRegisterMode() {
// Capture Port 3 register state in one single CPU cycle
uint32_t port3State = R_PORT3->PIDR;

// Isolate bit 1 (Pin 2) and bit 2 (Pin 3) using shifting and bitwise AND masking int MSB = (port3State >> 1) & 0x01;
int LSB = (port3State >> 2) & 0x01;
int encoded = (MSB << 1) | LSB;
int sum = (lastEncoded << 2) | encoded;

if(sum == 0b0010 || sum == 0b1011 || sum == 0b1101 || sum == 0b0100) encoderPos++; if(sum == 0b0001 || sum == 0b0111 || sum == 0b1110 || sum == 0b1000) encoderPos--;

lastEncoded = encoded;
}

•

•

•

Advanced Engineering Notes: Haptic Systems & Register-Level Control | Page 4

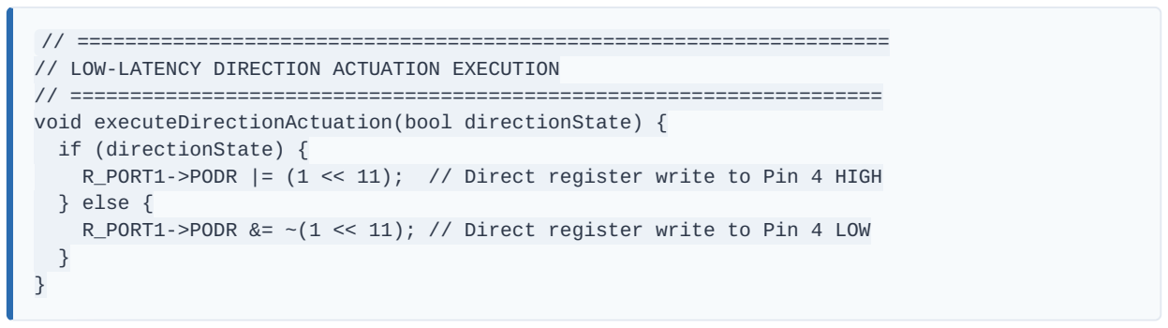
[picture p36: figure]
// ==================================================================== // LOW-LATENCY DIRECTION ACTUATION EXECUTION // ==================================================================== void executeDirectionActuation(bool directionState) { if (directionState) {; } else {

R_PORT1->PODR |= (1 << 11); // Direct register write to Pin 4 HIGH

R_PORT1->PODR &= ~(1 << 11); // Direct register write to Pin 4 LOW

## Section 8: Physical Hardware Connection Blueprints & Workspace Calibration

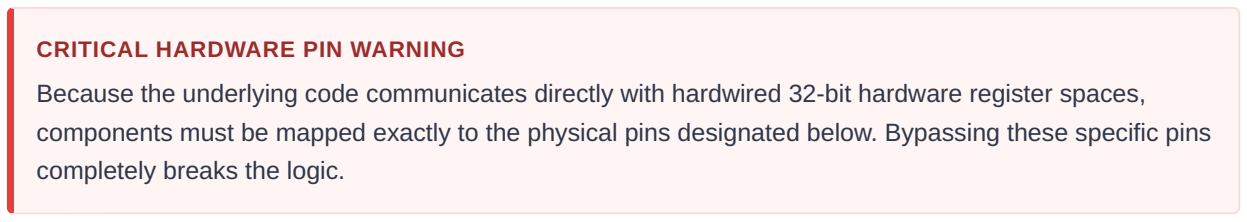
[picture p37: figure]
CRITICAL HARDWARE PIN WARNING; completely breaks the logic.

Because the underlying code communicates directly with hardwired 32-bit hardware register spaces, components must be mapped exactly to the physical pins designated below. Bypassing these specific pins

Driver Option A Blueprint: Cytron MD10C R3 (Sign-Magnitude Logic)
Arduino Uno R4 Pin 5 (Port 1, Pin 2) | → Cytron PWM Input (Carries high-speed 20 kHz pulses)
Arduino Uno R4 Pin 4 (Port 1, Pin 11) | → Cytron DIR Input (Drives direct register direction
changes)
Arduino Uno R4 GND Pin | → Cytron GND Terminal (Establishes uniform logic reference)
POWER + / - | → Tied directly to the respective positive and negative terminals of the 12V DC power
supply
MOTOR A / B → Tied directly to Motor Armature Terminal 1 and Terminal 2

Driver Option B Blueprint: L298N H-Bridge (Dual-Input Direction Logic)
Arduino Uno R4 Pin 5 (Port 1, Pin 2) → L298N ENA Pin (Remove local jumper block; carries 10 kHz pulses)
Arduino Uno R4 Pin 4 (Port 1, Pin 11) | → L298N IN1 Pin (Controls current vector Forward)
Arduino Uno R4 Pin 7 (Port 1, Pin 3) | → L298N IN2 Pin (Controls current vector Reverse)
Arduino Uno R4 GND Pin | → L298N GND Pin (Crucial: Tie Arduino ground and 12V supply ground
together here)
VCC (12V Terminal) → Connected to the positive (+) terminal of the 12V power supply

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
Advanced Engineering Notes: Haptic Systems & Register-Level Control | Page 5

Shared Quadrature Encoder Interface Mapping
Encoder VCC / GND | → Connected to the Arduino Uno R4 5V and GND power rails
Encoder Channel A (CLK) | → Pin 2 (Port 3, Pin 1 / Memory Register Bit: P301)
Encoder Channel B (DT) | → Pin 3 (Port 3, Pin 2 / Memory Register Bit: P302)

### 3. Workspace Calibration Protocol

If the entire setup is fully wired and powered, but moving the haptic handle past the 400-count boundary causes the motor to pull your hand deeper into the wall (instigating a destructive Positive Feedback Loop) instead of pushing back outward, do not alter your physical wire layout. Navigate to the top of your configuration script and toggle the boolean state flag:

const bool INVERT_MOTOR_DIRECTION = true; // Toggle to false if positive feedback occurs

This flag operation instantly realigns the microcontroller's mathematical force command matrix with your physical wiring topology without modifying your hardware bench space.

## Section 9: Core Glossary & Operational Terminology

H-Bridge Matrix — A solid-state switching network containing four discrete switching elements structured to govern current vector directions across an active inductive load, managing rotational spin directions.

Bootstrap Gate Drive — A capacitive pumping layout designed to capture low-side electrical charge to step up gate-drive potentials past the main supply voltage (VS

), forcing high-side N-channel DMOS elements into full saturation.

Stiction (Static Friction) — The mechanical breakaway friction threshold that a stationary shaft assembly must overcome before transitioning into continuous kinetic rotation.

Motor Stall Current — The peak electrical current consumed when an electric motor's shaft is physically restricted from rotating while full voltage is sustained. Under this condition, the windings act purely as a low-value static resistor.

Integral Windup / Sticky Integral — A control loop anomaly where a persistent error accumulates an excessively large integral term inside a PI/PID loop. Upon releasing the constraint, this historical error memory keeps the loop saturated, causing virtual haptic boundaries to feel sticky or glued.

State Resetting — A haptic control paradigm where historical tracking variables (like | integralError | ) are
instantaneously wiped to zero the moment a physical boundary condition changes, eliminating transition lag.

•
•
•
Advanced Engineering Notes: Haptic Systems & Register-Level Control | Page 6

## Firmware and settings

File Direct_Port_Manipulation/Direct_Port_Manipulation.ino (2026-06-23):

/**
 * ============================================================================
 * HIGH-PERFORMANCE 1-DOF HAPTIC VIRTUAL WALL CONTROL SYSTEM (SI CONVERTED)
 * Architecture: Bare-Metal Renesas RA4M1 (ARM Cortex-M4 @ 48 MHz)
 * Hardware Target: Arduino Uno R4 Minima + L298N H-Bridge Driver
 * * Hardware Mapping:
 * - Encoder Channel A (CLK): Arduino Pin 2 -> Native P301 (Port 3, Pin 1)
 * - Encoder Channel B (DT):  Arduino Pin 3 -> Native P302 (Port 3, Pin 2)
 * - Motor Driver Enable (PWM):Arduino Pin 5 -> Native P102 (Port 1, Pin 2) [GPT2]
 * - Motor Driver Direction 1: Arduino Pin 4 -> Native P111 (Port 1, Pin 11)
 * - Motor Driver Direction 2: Arduino Pin 7 -> Native P103 (Port 1, Pin 3)
 * ============================================================================
 */

// --- PHYSICAL HARDWARE CONFIGURATION ---
const float ENCODER_PPR = 400.0f;
const float ENCODER_CPR = ENCODER_PPR * 4.0f;       // 1600 Counts/Rev via 4x decoding
const float TWO_PI = 6.28318530f;

// --- GLOBAL MECHATRONIC TUNING PARAMETERS (SI UNITS) ---
const uint32_t PWM_FREQUENCY_HZ = 12000;            // Optimal range for L298N: 8000 Hz - 16000 Hz
const float WALL_THRESHOLD_RAD = 1.57079632f;       // Wall boundary at exactly 90 degrees (pi/2 radians)
const float K_STIFFNESS_SI = 8.5f;                  // Virtual Spring Stiffness (Newton-meters per Radian)
const float B_DAMPING_SI = 0.08f;                   // Virtual Damping Coefficient (Newton-meter-seconds per Radian)
const float MAX_CONTROL_TORQUE = 0.35f;             // Peak torque scaling factor for your motor setup (N-m)
const int MAX_PWM_OUTPUT = 255;                     // Bound for 8-bit user scaling logic
const bool INVERT_MOTOR_DIRECTION = true;           // Software toggle to correct force direction

// --- VOLATILE SHARED INTERRUPT VARIABLES ---
volatile long encoderPos = 0;
volatile int lastEncoded = 0;

// --- CONTROL LOOP TIMING SYSTEM ---
unsigned long lastTimeMicros = 0;
long lastRawPosition = 0; 
const unsigned long SAMPLE_INTERVAL_MICROS = 1000;  // Fixed 1 kHz Discrete Execution Loop
int telemetryCounter = 0;

// --- DIGITAL FILTERING COEFFICIENTS (2nd-Order Butterworth @ 1kHz) ---
const float b0 = 0.067455, b1 = 0.134911, b2 = 0.067455;
const float a1 = -1.142981, a2 = 0.412802;
float x_hist[2] = {0.0, 0.0};                       // Input velocity history registers [n-1, n-2]
float y_hist[2] = {0.0, 0.0};                       // Output filtered velocity history registers [n-1, n-2]

// --- HARDWARE TIMER CALCULATED CONSTANTS ---
uint32_t timerPeriodCounts = 0;                     // Stores dynamic GTPR overflow ceiling

// Forward Declarations
void actuateMotorL298NRaw(float forceCommand);
void updateEncoderRegisterMode();

void setup() {
  // Calculate hardware counting ceiling based on the 48 MHz peripheral clock
  timerPeriodCounts = 48000000 / PWM_FREQUENCY_HZ;

  // 1. CONFIGURE DIGITAL OUTPUTS (Port 1 Direction Register)
  // Turn Pin 4 (P111) and Pin 7 (P103) into Outputs
  R_PORT1->PDR |= (1 << 11) | (1 << 3);

  // 2. CONFIGURE DIGITAL INPUTS (Port 3 Direction Register)
  // Clear Bits 1 and 2 of Port 3 to establish inputs for Pins 2 and 3
  R_PORT3->PDR &= ~((1 << 1) | (1 << 2));
  
  // Enable internal Pull-Up Resistors via the Pin Function Select (PFS) registers
  R_PFS->PORT[3].PIN[1].PmnPFS_b.PCR = 1; // Pin 2 Pull-Up
  R_PFS->PORT[3].PIN[2].PmnPFS_b.PCR = 1; // Pin 3 Pull-Up

  // 3. ROUTE PERIPHERAL HARDWARE TIMER TO PIN 5
  // Route Pin 5 (P102) to General Purpose Timer 2 (GPT2) output
  R_PFS->PORT[1].PIN[2].PmnPFS_b.PSEL = 0b00011; // Assign function to GPT
  R_PFS->PORT[1].PIN[2].PmnPFS_b.PMR  = 1;       // Activate peripheral mode on pin

  // 4. CONFIGURE GENERAL PURPOSE TIMER 2 (GPT2) REGISTER MAP
  R_GPT2->GTCR_b.CST = 0;       // Stop timer during initialization configuration
  R_GPT2->GTCR_b.MD = 0b000;    // Select Sawtooth wave mode (Periodic counting)
  R_GPT2->GTCR_b.TPCS = 0b000;  // Use undivided master clock frequency (48 MHz)
  R_GPT2->GTPR = timerPeriodCounts; // Inject calculated overflow ceiling into GTPR
  R_GPT2->GTCCR[1] = 0;         // Start with clear Compare Register (0% initial duty cycle)
  R_GPT2->GTIOR = 0x00001F00;   // Force output pin HIGH on cycle start, LOW on match
  R_GPT2->GTCNT = 0;            // Zero out current stopwatch count
  R_GPT2->GTCR_b.CST = 1;       // Arm and start GPT2 hardware timer instantly

  // 5. INITIALIZE QUADRATURE ENCODER STATE SENSING
  uint32_t initialPort3 = R_PORT3->PIDR;
  int initialMSB = (initialPort3 >> 1) & 0x01; 
  int initialLSB = (initialPort3 >> 2) & 0x01; 
  lastEncoded = (initialMSB << 1) | initialLSB;

  // Attach execution triggers to standard hardware pin vectors (Ensures full 4x edge catching)
  attachInterrupt(digitalPinToInterrupt(2), updateEncoderRegisterMode, CHANGE);
  attachInterrupt(digitalPinToInterrupt(3), updateEncoderRegisterMode, CHANGE);

  Serial.begin(115200);
  lastTimeMicros = micros();
}

void loop() {
  unsigned long currentTimeMicros = micros();
  
  // Enforce rigid, deterministic 1 kHz control step interval
  if (currentTimeMicros - lastTimeMicros >= SAMPLE_INTERVAL_MICROS) {
    long currentRawPos;

    // ATOMIC GUARD SEGMENT: Safeguard shared volatile data against race conditions
    __disable_irq();
    currentRawPos = encoderPos;
    __enable_irq();

    // Calculate sample timeframe delta (dt = 0.001s)
    float dt = (float)SAMPLE_INTERVAL_MICROS / 1000000.0f; 
    
    // PHYSICAL STATE TRANSFORMATION: Convert raw encoder values directly to Radians
    float theta = ((float)currentRawPos / ENCODER_CPR) * TWO_PI;

    // Calculate raw velocity in Radians per Second
    long deltaCounts = currentRawPos - lastRawPosition; 
    float rawVelocityRadSec = (((float)deltaCounts / ENCODER_CPR) * TWO_PI) / dt;

    // DIGITAL SIGNAL PROCESSING: 2nd-Order Butterworth Filtered Velocity
    float filteredVelocityRadSec = (b0 * rawVelocityRadSec) + (b1 * x_hist[0]) + (b2 * x_hist[1]) 
                                 - (a1 * y_hist[0]) - (a2 * y_hist[1]);
    
    // Shift execution histories forward
    x_hist[1] = x_hist[0];             x_hist[0] = rawVelocityRadSec;   
    y_hist[1] = y_hist[0];             y_hist[0] = filteredVelocityRadSec;

    float wallTorque = 0.0f;

    // HAPTIC RENDERING BOUNDARY (Evaluated entirely in physical physics parameters)
    if (theta > WALL_THRESHOLD_RAD) {
      float penetrationDepthRad = theta - WALL_THRESHOLD_RAD;
      
      float springTorque = K_STIFFNESS_SI * penetrationDepthRad;
      float dampingTorque = B_DAMPING_SI * filteredVelocityRadSec;
      
      // Calculate resulting opposing force vector (Torque = -(K*x + B*v))
      wallTorque = -(springTorque + dampingTorque);
      
      // PASSIVITY GUARD CONSTRAINT: Force must only push back, never pull inward
      if (wallTorque > 0.0f) wallTorque = 0.0f; 
    }

    // ACTUATOR SCALING INTERFACE: Normalize physical torque into 8-bit PWM values
    float normalizedEffort = wallTorque / MAX_CONTROL_TORQUE;
    float wallForcePwm = normalizedEffort * (float)MAX_PWM_OUTPUT;

    // Pass force payload directly down to physical motor control registers
    actuateMotorL298NRaw(wallForcePwm);

    // High-Speed Serial Telemetry Output (Throttle execution rate to 40 Hz)
    telemetryCounter++;
    if (telemetryCounter >= 25) {
      int activePwm = abs((int)wallForcePwm);
      if (activePwm > MAX_PWM_OUTPUT) activePwm = MAX_PWM_OUTPUT;
      
      Serial.print("AngleRad:");    Serial.print(theta, 3);
      Serial.print(",VelRadSec:");  Serial.print(filteredVelocityRadSec, 2);
      Serial.print(",TorqueNm:");   Serial.print(wallTorque, 4);
      Serial.print(",DutyCycle:");  Serial.print(((float)activePwm / 255.0f) * 100.0f, 1);
      Serial.println("%");
      telemetryCounter = 0;
    }

    // Save cycle states for next loop execution
    lastRawPosition = currentRawPos;
    lastTimeMicros = currentTimeMicros;
  }
}

/**
 * Bare-Metal Motor Power Control Function
 * Accepts calculated force vector, sets H-Bridge switches, and dynamically scales PWM duty cycle.
 */
void actuateMotorL298NRaw(float forceCommand) {
  int pwmValue = abs((int)forceCommand);
  if (pwmValue > MAX_PWM_OUTPUT) pwmValue = MAX_PWM_OUTPUT;
  
  bool directionFlag = (forceCommand > 0);
  if (INVERT_MOTOR_DIRECTION) directionFlag = !directionFlag;

  // DIRECT PORT MANIPULATION: Safe Bitmasking execution via PODR registers
  if (pwmValue == 0) {
    // Engage H-Bridge Brake State by pulling both direction lines LOW simultaneously
    R_PORT1->PODR &= ~((1 << 11) | (1 << 3)); 
  } else if (directionFlag) {
    // Pin 4 (P111) HIGH, Pin 7 (P103) LOW
    R_PORT1->PODR |= (1 << 11);
    R_PORT1->PODR &= ~(1 << 3);
  } else {
    // Pin 4 (P111) LOW, Pin 7 (P103) HIGH
    R_PORT1->PODR &= ~(1 << 11);
    R_PORT1->PODR |= (1 << 3);
  }

  // PROPORTIONAL CEILING SCALING MATH: Translates 8-bit command into current timer period counts
  uint32_t compareValue = (uint32_t)((float)pwmValue * ((float)timerPeriodCounts / 255.0f));
  
  // Inject calculated duty tripwire register directly into GPT2 compare buffer channel
  R_GPT2->GTCCR[1] = compareValue; 
}

/**
 * Interrupt Service Routine: Handled at bare-metal execution speeds.
 * Rapidly reads Port 3 input pins to determine quadrature gray code state transitions.
 */
void updateEncoderRegisterMode() {
  // Sample a snapshot of all inputs on Port 3 in a single cycle
  uint32_t port3State = R_PORT3->PIDR;
  
  // Isolate Pin 1 (Bit 1) and Pin 2 (Bit 2) state via single-step bit shifting and masks
  int MSB = (port3State >> 1) & 0x01; 
  int LSB = (port3State >> 2) & 0x01; 
  
  int encoded = (MSB << 1) | LSB; 
  int sum = (lastEncoded << 2) | encoded; 
  
  // Evaluate Gray Code Quadrature State Machine Table (4x Decoded States)
  if(sum == 0b0010 || sum == 0b1011 || sum == 0b1101 || sum == 0b0100) encoderPos++;
  if(sum == 0b0001 || sum == 0b0111 || sum == 0b1110 || sum == 0b1000) encoderPos--;
  
  lastEncoded = encoded; 
}

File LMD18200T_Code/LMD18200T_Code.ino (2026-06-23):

/**
 * 1-DOF Cascaded Current-Controlled Haptic System
 * Hardware: Arduino Uno R4 Minima, LMD18200T, RS-555PH
 * Architecture: 1kHz Outer Haptic Loop -> Inner PI Current Loop
 */

// --- Pin Definitions ---
const int clkPin = 2;   // Encoder Phase A
const int dtPin = 3;    // Encoder Phase B
const int DIR_PIN = 4;  // LMD18200T Direction (Pin 3)
const int PWM_PIN = 5;  // LMD18200T PWM (Pin 5)
const int CURRENT_SENSE_PIN = A0; // LMD18200T Current Sense (Pin 8) via RC Filter

// --- Encoder Variables ---
volatile long encoderPos = 0;
volatile int lastEncoded = 0;

// --- Timing & Loop Control ---
unsigned long lastTimeMicros = 0;
long lastRawPosition = 0; 
const unsigned long SAMPLE_INTERVAL_MICROS = 1000; // 1 millisecond (1 kHz loop)
int telemetryCounter = 0;

// --- 2nd-Order Butterworth Filter (fc = 100Hz, fs = 1000Hz) ---
const float b0 = 0.067455;
const float b1 = 0.134911;
const float b2 = 0.067455;
const float a1 = -1.142981;
const float a2 = 0.412802;

float x_hist[2] = {0.0, 0.0};
float y_hist[2] = {0.0, 0.0};

// --- Hardware Constants ---
const float RS_OHMS = 2200.0;       // 2.2k Ohm sense resistor
const float SENSE_RATIO = 0.000377; // 377 uA per Amp

// --- PI Current Controller Parameters ---
float Kp_curr = 25.0;     // Proportional gain
float Ki_curr = 500.0;    // Integral gain
float integralError = 0.0;
const float MAX_INTEGRAL = 200.0; // Anti-windup limit

// --- Haptic Physics Parameters ---
const long WALL_POSITION_COUNTS = 400;  
const float K_STIFFNESS = 0.05;  // Output is now in Amps, keep this low initially!
const float B_DAMPING = 0.002; 
// --- SAFETY LIMITS ---
const float MAX_CURRENT_AMPS = 0.3; // Limit to 0.3A to save the capacitor
const int MAX_PWM_LIMIT = 100;      // Limit PWM to 100 (out of 255)

void setup() {
  // Configure LMD18200T Logic Pins
  pinMode(DIR_PIN, OUTPUT);
  pinMode(PWM_PIN, OUTPUT);
  
  // Configure Encoder Pins
  pinMode(clkPin, INPUT_PULLUP);
  pinMode(dtPin, INPUT_PULLUP);
  
  // Uno R4 allows higher ADC resolution for cleaner current sensing
  analogReadResolution(12); // Sets analogRead range to 0-4095

  // Initialize Encoder State
  int MSB = digitalRead(clkPin); 
  int LSB = digitalRead(dtPin); 
  lastEncoded = (MSB << 1) | LSB;

  // Attach Interrupts for 4x Quadrature Decoding
  attachInterrupt(digitalPinToInterrupt(clkPin), updateEncoder, CHANGE);
  attachInterrupt(digitalPinToInterrupt(dtPin), updateEncoder, CHANGE);

  Serial.begin(115200);
  lastTimeMicros = micros();
}

void loop() {
  unsigned long currentTimeMicros = micros();
  
  // Enforce strict 1 millisecond execution clock
  if (currentTimeMicros - lastTimeMicros >= SAMPLE_INTERVAL_MICROS) {
    long currentRawPos;
    
    // Atomic Read: Safely snapshot encoder ticks
    noInterrupts();
    currentRawPos = encoderPos;
    interrupts();

    // 1. Calculate and Filter Velocity
    float dt = (currentTimeMicros - lastTimeMicros) / 1000000.0;
    long deltaCounts = currentRawPos - lastRawPosition; 
    float rawVelocityCounts = (float)deltaCounts / dt;

    float filteredVelocityCounts = (b0 * rawVelocityCounts) + (b1 * x_hist[0]) + (b2 * x_hist[1]) 
                                 - (a1 * y_hist[0]) - (a2 * y_hist[1]);

    // Shift discrete time delay history registers
    x_hist[1] = x_hist[0];     
    x_hist[0] = rawVelocityCounts;   
    y_hist[1] = y_hist[0];     
    y_hist[0] = filteredVelocityCounts;

    // 2. Outer Loop: Haptic Virtual Wall -> Target Current
    float targetCurrentAmps = 0.0;
    
    if (currentRawPos > WALL_POSITION_COUNTS) {
      long penetration = currentRawPos - WALL_POSITION_COUNTS;
      float springForce = K_STIFFNESS * penetration;
      float dampForce = B_DAMPING * filteredVelocityCounts;
      
      // Calculate opposing force
      targetCurrentAmps = -(springForce + dampForce);
      
      // Passivity guard: Wall pushes out, it never pulls you in
      if (targetCurrentAmps > 0.0) targetCurrentAmps = 0.0;
    } else {
      // Free space
      targetCurrentAmps = 0.0;
      integralError = 0.0;
    }

    // Clamp target current for motor/driver safety
    if (targetCurrentAmps < -MAX_CURRENT_AMPS) targetCurrentAmps = -MAX_CURRENT_AMPS;
    if (targetCurrentAmps > MAX_CURRENT_AMPS) targetCurrentAmps = MAX_CURRENT_AMPS;

    // 3. Inner Loop: PI Current Controller
    float actualCurrentAmps = readMotorCurrent();
    
    // Calculate error (comparing magnitudes)
    float currentError = abs(targetCurrentAmps) - actualCurrentAmps;
    
    // Proportional Term
    float pTerm = Kp_curr * currentError;
    
    // Integral Term with Anti-Windup
    integralError += currentError * dt;
    if (integralError > MAX_INTEGRAL) integralError = MAX_INTEGRAL;
    if (integralError < -MAX_INTEGRAL) integralError = -MAX_INTEGRAL;
    float iTerm = Ki_curr * integralError;
    
    // Calculate final PWM control effort (0-255 mapped from PI output)
    float controlEffort = pTerm + iTerm;
    
    int pwmOutput = (int)controlEffort;
    
    // Clamp PWM to 8-bit bounds
    if (pwmOutput > 255) pwmOutput = 255;
    if (pwmOutput < 0) pwmOutput = 0;

    // 4. Actuate H-Bridge
    // Direction logic based on the sign of targetCurrentAmps
    if (pwmOutput > MAX_PWM_LIMIT) pwmOutput = MAX_PWM_LIMIT; // Apply the safe limit
    if (targetCurrentAmps < 0) {
      digitalWrite(DIR_PIN, LOW); // Entering wall (pushing back)
    } else {
      digitalWrite(DIR_PIN, HIGH);
    }
    analogWrite(PWM_PIN, pwmOutput);

    // 5. Downsampled Telemetry Monitor (Runs at 40Hz)
    telemetryCounter++;
    if (telemetryCounter >= 25) {
      Serial.print("Pos:"); 
      Serial.print(currentRawPos);
      Serial.print("\tTarget_A:"); 
      Serial.print(targetCurrentAmps, 3);
      Serial.print("\tActual_A:"); 
      Serial.print(actualCurrentAmps, 3);
      Serial.print("\tPWM:"); 
      Serial.println(pwmOutput);
      
      telemetryCounter = 0;
    }

    // Cache state variables for the next iteration step
    lastRawPosition = currentRawPos;
    lastTimeMicros = currentTimeMicros;
  }
}

/**
 * Reads the analog voltage from the LMD18200T current sense pin
 * and converts it into actual motor current in Amperes.
 */
float readMotorCurrent() {
  // Read 12-bit ADC (0-4095 corresponds to 0-5V)
  int rawADC = analogRead(CURRENT_SENSE_PIN);
  float voltage = (rawADC / 4095.0) * 5.0;
  
  // Imotor = V_ADC / (Rs * 377uA)
  float currentAmps = voltage / (RS_OHMS * SENSE_RATIO);
  
  // Quick safety guard to prevent tiny ADC noise from registering as current
  if (currentAmps < 0.25) currentAmps = 0.0;
  
  return currentAmps;
}
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

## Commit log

2026-06-10 Initial Commit - Upon Completion of week 1 - Minor Project
    [Base_coupler_shaft.stl, Base_coupler_shaft_1.stl, Coupler-Shaft-1.stl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]
2026-06-23 Week 3.
    [Base_coupler_shaft_2.stl]
2026-06-25 Implemented FO-Kelvin Voigt and Currently Implementing FO-SLS Model, 2026
2026-07-06 Added all the drawings.
    [Base_coupler_shaft.stl, Base_coupler_shaft_1.stl, Base_coupler_shaft_2.stl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]
2026-07-06 Revise README with project details and structure
    Expanded project overview and repository structure. Updated hardware wiring details and core engineering insights. Added sections on performance parameters and research topics covered.
